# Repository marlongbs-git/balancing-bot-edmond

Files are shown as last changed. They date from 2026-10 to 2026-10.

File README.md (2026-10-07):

# edmond: the self-balancing robot!

Edmond is a two-wheeled inverted-pendulum robot built around an **STM32F303K8 (Nucleo-32)**. He balances using **LQR state feedback** designed in MATLAB/Simulink, with sensor fusion from an MPU6050, a custom 3D-printed chassis, and an OLED face that reacts when he falls.

<p align="center">
  robot_balancing_updatedgif
</p>

| | |
|---|---|
| **Controller** | Discrete LQR (`dlqr`) on `[x, ẋ, θ, θ̇]` |
| **MCU** | STM32F303K8 (Cortex-M4F, 64 KB flash) |
| **Sensing** | MPU6050 IMU (I2C) + quadrature encoders |
| **Actuation** | 2x DFRobot FIT0450 geared DC motors, L298N-based driver |
| **Extras** | Fall detection, SSD1306 OLED face |
| **Tools** | STM32CubeIDE, MATLAB/Simulink, SolidWorks |

---

## Contents

- [How edmond works](#how-he-works)
- [Repository layout](#repository-layout)
- [Firmware](#firmware)
- [Electronics](#electronics)
- [Control design](#control-design)
- [Mechanical design](#mechanical-design)
- [What I learned](#what-i-learned)
- [Status and roadmap](#status-and-roadmap)
- [Credits](#credits)

---

## How he works

Every control cycle the firmware:

1. Reads the accelerometer and gyro over I2C and fuses them with a **complementary filter** to get the pitch angle `θ` and rate `θ̇`.
2. Reads the wheel encoders for position `x` and velocity `ẋ`.
3. Computes the control effort `u = -K·[x ẋ θ θ̇]ᵀ`.
4. Converts `u` (a force) to a motor duty cycle using the motor's electrical model (torque, back-EMF, supply voltage).
5. Drives the H-bridge, or cuts power and shows the "fallen" face if the tilt exceeds the fall threshold.

## Repository layout

```
├── firmware/       STM32CubeIDE project (.ioc, Core/Src, Core/Inc)
├── electronics/    Pinout, wiring diagram, bill of materials
├── matlab/         Plant model, LQR design, Simulink model
├── mechanical/     SolidWorks parts and assembly, STEP and STL exports
├── docs/           Longer write-ups (sensor fusion, motor model, I2C debugging)
└── media/          Photos, renders, demo GIF
```

## Firmware

C on STM32 HAL. The code is split into small modules:

| File | Responsibility |
|---|---|
| `mpu6050.c/.h` | I2C driver, register reads, calibration, digital and complementary filter |
|`fit0450encoder.c/.h`| Encoder data, wheel velocity, wheel position |
| `robot_state.c/.h` | Combines IMU and encoder data into one `RobotState` |
| `control.c/.h` | LQR gains, force-to-duty conversion, PWM output |
| `ssd1306.c/.h` | Normal and fallen faces, drawn only on state changes |

See [`firmware/`](firmware/) for build instructions.

## Electronics

Pin assignments and wiring live in [`electronics/pinout.md`](electronics/pinout.md).
<p align="center">
edmond_electronicsbringup
</p>

- The MPU6050 and OLED share one I2C bus (different addresses).
- The robot is powered from a single supply through a 5 V buck converter into the Nucleo.
- I2C reliability took real effort: loose connectors caused intermittent failures, so the final build is soldered. The bus-recovery routine is documented in [`docs/i2c-debugging.md`](docs/i2c-debugging.md).

## Control design

The plant is modeled as a cart-pendulum with the wheels as the cart and the chassis as the pendulum body, including its moment of inertia. The model is linearized about the upright position, discretized, and fed to `dlqr`.

<p align="center">
cart_pend
LQR
</p>

- **State:** `[x, ẋ, θ, θ̇]`
- **Weights:** `Q` penalizes angle and angular rate much more than position; `R` penalizes motor effort.
- **Physical parameters** (masses, center of mass, inertia) come from the SolidWorks mass-properties report.

Details and the derivation are in [`matlab/`](matlab/)

## Mechanical design

The chassis is 3D printed in PLA and holds the two motors, the electronics deck, and the OLED.

<p align="center">
edmond_exploded2
front 
</p>

STEP and STL exports are in [`mechanical/`](mechanical/).

## What I learned

- Bit-level I2C register handling, and why a silent read failure is worse than a loud one.
- Why unit mismatches (degrees vs radians) are the fastest way to saturate a motor.
- How to get real physical parameters out of CAD instead of guessing them.
- Controllers can be limited by actuation, motor deadband, back-EMF spikes, and why power-supply details matter.

## Status and roadmap

- [x] Balances unaided (standing on business!)
- [x] Recovers from small pushes
- [x] Fall detection with OLED face
- [ ] Extended Kalman filter for attitude estimation
- [ ] Battery power
- [ ] Custom Motor Driver and PCB to replace perfboard

## Credits

- Phil's Lab (STM32 implementation and digital filter tutorials)
- Steve Brunton's Control Bootcamp (control and state-space modeling lectures), *Data Driven Science & Engineering
  Machine Learning, Dynamical Systems, and Control* 
- Beard and McLain, *Small Unmanned Aircraft* (attitude estimation)
- Brian Douglas's MATLAB Tech Talks (Discrete Control Theory)
- SSD1306 Files from [afiskon/stm32-ssd1306](https://github.com/afiskon/stm32-ssd1306) for OLED Drivers and face from [mjyc/table-robot-face](https://github.com/mjyc/tablet-robot-face)

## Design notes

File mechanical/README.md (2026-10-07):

# Mechanical design

The chassis is designed in SolidWorks and 3D printed in PLA. It holds the two geared motors, the electronics deck (Nucleo, MPU6050, perfboard), and the OLED face. The assembly is `robot_assemblyV4`.

<p align = "center" >
isometric
front
edmond_exploded2
</p>

## Contents

- [Files](#files)
- [Design overview](#design-overview)
- [Fasteners](#fasteners)
- [Mass properties](#mass-properties)
- [Accelerometer calibration jig](#accelerometer-calibration-jig)
- [Assembly notes](#assembly-notes)

---

## Files

| Folder / file | What it is |
|---|---|
| `*.SLDPRT`, `*.SLDASM` | Native SolidWorks parts and the full assembly |
| `stl/` | STL files for 3D printing |

## Design overview

- **Rigid body.** The legs tilt together with the head. The whole chassis is the pendulum body in the control model, and only the wheels act as the cart.
- **Motors in the legs.** The two DFRobot FIT0450 geared motors sit low, one per leg, with the wheels on their output shafts.
- **Electronics deck on top.** The Nucleo and the MPU6050 sit on a perfboard, and the OLED is mounted at the front so the face is visible.
- **Printed in PLA.** All structural parts are 3D printed.

## Fasteners

Two metric sizes are used throughout:

| Size | Typical use |
|---|---|
| **M3** | Structural joints, motor mounting, wheel and leg hardware |
| **M2** | Small electronics mounts: perfboard, OLED, sensor board |
| **M3 Heat-Set Inserts** | Leg and Head Interfacing

Using only two sizes keeps the build simple: a single hex key and screwdriver set, and no mixing of thread standards.

## Mass properties

Taken from SolidWorks (**Evaluate → Mass Properties**) relative to a coordinate system at the wheel axle, with its **X axis along the axle**, which is the axis the robot tips about.

| Property | Value |
|---|---|
| Mass (pendulum body, without wheels) | 291.35 g |
| Wheel mass (both) | 40 g |
| Center of mass (X, Y, Z) | −65.85, 60.43, −2.22 mm |
| Moment of inertia about the COM, along the axle (`Lxx`) | 604,748 g·mm² |

These values feed directly into the control model. See [`../matlab/README.md`](../matlab/README.md) for how `L` and `I` are derived from them.

## Accelerometer calibration jig

A small 3D-printed jig for calibrating the MPU6050 accelerometer. An accelerometer at rest should read exactly 1 g on whichever axis points along gravity and 0 on the other two, but real boards are off by a small amount per axis. The jig holds the sensor in repeatable, known orientations so the offsets can be measured instead of guessed.

<p align = "center" >




</p>

### Why a jig

Hand-holding the board against a table gives slightly different angles every time, and a tilt of even a degree or two shows up as an error in the offset. A printed jig with flat, square faces makes each calibration pose repeatable. It also pairs with the firmware routine, which asks for one pose per axis.

### How it is used

The firmware routine `getAccelerometerOffsets()` walks through the three axes over the serial port (USART2). For each axis:

1. It prints a prompt telling you which pose to put the board in. The X axis prompt is *"Lay Flat on Side"* and the Y axis prompt is *"Lay Flat on Back"*, followed by the Z axis pose.
2. A 5-second countdown gives you time to place the jig and let it settle.
3. It reads the accelerometer 10 times at 100 ms intervals and averages the samples.
4. It stores `offset = 1 − average` (in g) for that axis.

The three offsets are printed at the end, and they are added to the raw readings in the pitch calculation.

| Step | Pose | Axis calibrated |
|---|---|---|
| 1 | Jig on its side | X |
| 2 | Jig on its back | Y |
| 3 | Jig flat | Z |

### Axis convention

Using the jig showed that the sensor's X and Y axes are swapped relative to the robot's frame. Pitch is therefore computed with

```c
anglePitch = atan2(y_accel, sqrt(x_accel*x_accel + z_accel*z_accel)) * (180 / M_PI);
```

and the gyro rate about X is used with it. The jig is what made this visible: with the board in a known pose, the axis that read 1 g was not the one expected.

### Is it needed again?

No. The calibration only needs to be done once per sensor. After running it, the offsets were hard-coded in the firmware, so the jig is not needed to run the robot. Re-run it if the MPU6050 is replaced or re-soldered at a different angle.

### Files and print notes

- STL: `robotcalibrationjig.stl`

## Assembly notes

- Keep the center of mass centered between the wheels, so the robot tips straight and doesn't drift sideways.
- Re-run **Mass Properties** whenever you add, move, or change parts. The `m`, `L` and `I` values in the control model depend on it, and a new gain vector may be needed.
- Check that the encoder and motor wires do not rub against the wheels.

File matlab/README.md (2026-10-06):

# MATLAB / Simulink: model and LQR design

Everything needed to go from the robot's CAD mass properties to the gain vector `Kdlqr` that runs on the STM32.

**Pipeline:** SolidWorks mass properties → linearized cart-pendulum model `(A, B)` → controllability and observability checks → discretize at `Ts = 0.04 s` → discrete LQR (`dlqr`) → closed-loop pole check → Simulink simulation → paste `Kdlqr` into the firmware.

## Contents

- [Files](#files)
- [How to run](#how-to-run)
- [The model](#the-model)
- [Parameters and where they come from](#parameters-and-where-they-come-from)
- [Getting the inertia out of SolidWorks](#getting-the-inertia-out-of-solidworks)
- [LQR design](#lqr-design)
- [Results](#results)
- [Simulink model](#simulink-model)
- [Using the gains in the firmware](#using-the-gains-in-the-firmware)
- [Assumptions and limitations](#assumptions-and-limitations)
- [References](#references)

---

## Files

| File | What it is |
|---|---|
| `implementation.mlx` | **The design script for this robot.** Parameters, `A` and `B`, controllability and observability, `lqr`, `c2d`, `dlqr`, discrete pole plot. Produces `Kdlqr`. |
| `self_balancing_discreteimplementation.slx` | Simulink model of the discrete closed loop. Reads its variables from the workspace, so run `implementation.mlx` first. |
| `documentation.mlx` | Study notes following Steve Brunton's cart-pendulum example: pole placement, LQR, Kalman filter, LQG, S-Function nonlinear simulation. It uses Brunton's textbook values (`m = 1`, `M = 5`, `L = 2`), **not** this robot's parameters. |

**Requirements:** MATLAB with Control System Toolbox (`lqr`, `dlqr`, `c2d`, `ctrb`, `obsv`) and Simulink.

## How to run

1. Open `implementation.mlx` and click **Run**. It defines every variable the Simulink model needs: `F`, `G`, `Kdlqr`, `x0`, `Ts`, `Cd_simulink`, `Dd_simulink`.
2. Open `self_balancing_discreteimplementation.slx` and run it. The Scope shows the four states recovering from the initial tilt `x0`.
3. To change the starting tilt, edit `x0 = [0; 0; deg2rad(10); 0]` in the script and run it again.

## The model

The robot is a cart-pendulum. The **wheels are the cart** (mass `M`), and the **chassis, motors, electronics and head are the pendulum body** (mass `m`). The body has its own center of mass and moment of inertia, so it is not an ideal point mass on a massless rod.

State and input:

```
x = [ x   ẋ   θ   θ̇ ]ᵀ        u = force on the cart (N)
x   cart (wheel) position       θ   body angle from upright (rad)
```

Linearized about the upright position (θ = 0), with `p = I(M + m) + M m L²`:

```
      ⎡ 0    1                   0                 0 ⎤        ⎡ 0           ⎤
A  =  ⎢ 0  -(I + mL²) d / p    m² g L² / p         0 ⎥   B =  ⎢ (I + mL²)/p ⎥
      ⎢ 0    0                   0                 1 ⎥        ⎢ 0           ⎥
      ⎣ 0  -(m L d) / p        m g L (M + m) / p    0 ⎦        ⎣ m L / p     ⎦
```

Sanity check: setting `I = 0` collapses this to Brunton's point-mass cart-pendulum matrices. Open-loop, the model has exactly one unstable pole (the falling pendulum), at about **+13.9 rad/s**.

## Parameters and where they come from

| Symbol | Value | Meaning | Source |
|---|---|---|---|
| `m` | 0.29135 kg | Pendulum body mass | SolidWorks mass of `robot_assemblyV4` (291.35 g) |
| `M` | 0.040 kg | Wheel (cart) mass | Weighed |
| `L` | 0.06047 m | Distance from the wheel axle to the body's center of mass | √(Y² + Z²) of the COM in `Coordinate System1` (60.43 mm, −2.22 mm) |
| `I` | 6.04748e-4 kg·m² | Body moment of inertia **about its own center of mass**, about the axle direction | SolidWorks `Lxx` at the COM = 604,748.13 g·mm² × 1e-9 |
| `d` | 1 | Cart damping | Estimated, a tuning value |
| `g` | 9.81 m/s² | Gravity | |
| `Ts` | 0.04 s | Control loop period | Firmware loop (must match, see below) |

## Getting the inertia out of SolidWorks

The inertia is computed in CAD, not guessed.
<p align = "center" > 
robot_coordinatesystem
</p>

1. Put a **coordinate system at the wheel axle**, with its **X axis along the axle**. The robot tips about this X axis.
2. Open **Evaluate → Mass Properties** and set *Report coordinate values relative to* to that coordinate system.
3. Read three things:
   - **Mass** → `m`
   - **Center of mass** (X, Y, Z). X is along the axle (it is about half the track width, because the origin sits on one wheel), so it does not affect the lever arm. The lever arm is `L = √(Y² + Z²)`.
   - **Moments of inertia taken at the center of mass and aligned with the output coordinate system** → `Lxx`, the moment about the axle direction.
4. Convert units: g·mm² × 1e-9 = kg·m².

**Why `Lxx` at the center of mass, and not `Ixx` at the axle?** The model contains `(I + m L²)`. That term is the parallel-axis theorem (the inertia about the axle). If `I` is already the axle value, the `m L²` is counted twice. Check: `6.04748e-4 + 0.29135 × 0.06047² = 1.670e-3 kg·m²`, which matches SolidWorks' `Ixx` at the axle (1,669,992 g·mm²).

## LQR design

Cost: minimize `Σ ( xᵀ Q x + R u² )`.

```matlab
Q = diag([50 1 100 100]);   % penalties on x, xdot, theta, thetadot
R = 100;                    % penalty on control effort
```

- `Q` punishes state error. The large angle and angular-rate weights make tilt the priority. Position is allowed to drift more.
- `R` punishes control effort. A larger `R` gives a gentler, slower controller and a smaller one a more aggressive controller. Only the ratio of `Q` to `R` matters.

Steps in the script:

1. `ss(A, B, C, D)` with `C = eye(4)` (all four states are measured: encoder for `x` and `ẋ`, filtered IMU for `θ` and `θ̇`).
2. `ctrb` and `obsv` checks: both rank 4.
3. `c2d(sysc, Ts, 'zoh')` with `Ts = 0.04`.
4. Re-check controllability and observability on `(F, G)`.
5. `[Kdlqr, Ks, Kp] = dlqr(F, G, Q, R)`, applied directly to the **discrete** system. (`lqr` on the continuous model is also computed, only for comparison.)
6. Verify stability: all eigenvalues of `F − G·Kdlqr` must have magnitude < 1.

<p align = "center">
continous2discrete
</p>
## Results

Closed-loop discrete poles, all inside the unit circle:

| Pole | Magnitude |
|---|---|
| 0.0810 | 0.0810 |
| 0.9714 | 0.9714 |
| 0.8970 ± 0.0465i | 0.8982 |

Gain vector (`u = −Kdlqr · [x ẋ θ θ̇]ᵀ`, SI units, angle in radians):

```
Kdlqr ≈ [ -0.2045   -1.4142    5.5034    0.4909 ]
```

<p align="center">
Discrete Closed-Loop Poles
simulinkblockdiagram
</p>
<p align = "center">
10degdisturbance
</p>

The Simulink runs start tilted at 10°, 20° and 30° with all states returning to zero.

## Simulink model

`self_balancing_discreteimplementation.slx` is a minimal discrete closed loop:

- **Discrete State Space** block: `A = F`, `B = G`, `C = Cd_simulink` (identity), `D = Dd_simulink`, initial condition `x0`, sample time `Ts`.
- **Gain** block (`−Kdlqr`, matrix multiply): state feedback `u = −K x` fed back into the plant.
- **Scope** and **To Workspace**: for viewing and exporting the state trajectories.

It simulates the **linear** model, so it answers "does the design stabilize the linearized plant?", not "will the real robot behave identically?".

## Using the gains in the firmware

1. Run `implementation.mlx` and read `Kdlqr` (add `disp(Kdlqr)` to print it).
2. Paste the four numbers into `setControlGains(...)` in `firmware/Core/Src/control.c`.
3. Keep the same state order `[x, ẋ, θ, θ̇]`, SI units, and angles in **radians**. The firmware stores the pitch in degrees and converts before applying `K`.
4. `Ts = 0.04` must match the actual control loop period, because the discrete gains depend on it. If the loop runs at a different rate, change `Ts` and re-run the script.
5. Convert force to motor duty with the motor model (see the firmware README).

## Assumptions and limitations

- The model is **linearized about upright**, valid for small angles.
- The only input is a force on the cart. The motor, driver and deadband are handled afterward by the force-to-duty conversion, not inside the LQR model.
- Damping `d` is an estimate, not a measured value.
- Wheel inertia is represented only through the cart mass `M`.
- No sensor noise or state estimator in the loop. The measured states come from the complementary filter and encoder directly.
- Tuning of `Q` and `R` was done by experiment on the robot, not by an optimization criterion.

## References

- Steven L. Brunton, *Control Bootcamp* lectures and *Data-Driven Science and Engineering* (cart-pendulum, LQR, LQG)
- University of Michigan CTMS, *Inverted Pendulum: System Modeling* (the form with body inertia `I`)
- MathWorks documentation: `lqr`, `dlqr`, `c2d`, `ctrb`, `obsv`

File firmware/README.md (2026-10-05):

# Firmware

STM32CubeIDE project for the self-balancing robot (STM32F303K8, Nucleo-32). C on the STM32 HAL.

## Contents

- [Overview](#overview)
- [Modules](#modules)
- [Control path](#control-path)
- [Setup and build](#setup-and-build)
- [Running and tuning](#running-and-tuning)
- [Challenges](#challenges)
- [Known limitations](#known-limitations)

---

## Overview

The main loop does the same thing every cycle:
<p align="center">
firmware_decision
</p>

## Modules

| Module | Responsibility |
|---|---|
| `mpu6050.c/.h` | I2C driver for the IMU: register reads (16-bit values assembled with bit shifts), calibration, accelerometer pitch, gyro rate, complementary filter, I2C error handling and bus recovery |
| `robot_state.c/.h` | Builds one `RobotState` (x, v, θ, ω, tipped) from the IMU and encoder. Everything downstream reads this struct |
| `control.c/.h` | LQR gains, control effort, force-to-duty conversion, deadband handling, PWM and direction output |
| `ssd1306` + face code | OLED driver and the two face bitmaps. Redrawn only when the fallen/normal state changes |
| `main.c` | Peripheral init (generated by CubeMX) and the control loop |

## Control path

| Function | What it does |
|---|---|
| `getRobotState()` | Returns the latest fused state. Single entry point for sensor data |
| `updateOrientationState()` | Reads accel and gyro once each, runs `compFilter()`, stores θ and θ̇ |
| `compFilter(accelAngle, gyroRate, alpha)` | `θ = α(θ + gyro·dt) + (1−α)·θ_accel`. Guards the first call and clamps `dt` |
| `setControlGains(kx, kv, ktheta, komega)` | Loads the gains from the MATLAB LQR design |
| `computeControlEffort(&state)` | `u = -K·x`. Converts degrees to radians first, because K was designed in radians |
| `computeControlDuty(u, v)` | Turns a force into a duty cycle using the motor model (below) |
| `setPWMControl(duty)` | Sign sets the direction pins, magnitude sets the `TIM1` compare value |
| `updateFaceDisplay(tipped)` | Draws a face only on a state change, to avoid blocking the I2C bus |
| `printRobotState(&state)` | UART debug output for plotting |

### Force to duty

LQR outputs a force at the wheel. The motor needs a voltage, so:

```c
wheelOmega = v / r;                                  // wheel speed from cart velocity
torque     = u * r;                                  // force -> wheel torque
V          = (torque + ktkvOverR * wheelOmega) / ktOverR;  // add back-EMF term
duty       = V / supplyVoltage;                      // normalise to PWM
```

Motor constants (FIT0450): `Ra ≈ 2.14 Ω`, `Kt ≈ 0.028 N·m/A`, `Kv ≈ 0.336 V·s/rad`.

The motor constants were gathered using calculations from [DFRobot's FIT0450 Datasheet](https://wiki.dfrobot.com/fit0450/#tech_specs)

### Fall detection

If `|θ|` exceeds the tilt threshold, `state.tipped` is set, PWM goes to zero and the fallen face is shown. `updateFaceDisplay()` is called every loop (outside the tipped branch) so the face returns to normal once the robot is upright again.

```c
#define FALL_THRESHOLD_DEGREES 40.0f
#define RECOVERY_THRESHOLD_DEGREES 5.0f
```

```c
static bool checkFallDetection(float thetaDeg) {
	static bool tippedLatch = false;

	if(!tippedLatch && fabs(thetaDeg) > FALL_THRESHOLD_DEGREES){
		tippedLatch = true;
	}else if (tippedLatch && fabs(thetaDeg) < RECOVERY_THRESHOLD_DEGREES){
		tippedLatch = false;
	}
	return tippedLatch;
}
```
## Setup and build

**Requirements:** STM32CubeIDE, an ST-LINK (built into the Nucleo), a serial terminal.

1. Clone the repo and open `firmware/` in STM32CubeIDE (*File → Open Projects from File System*).
2. Open the `.ioc` file to check the peripheral configuration. CubeMX is the source of truth for pins.
3. Build with the Release configuration (`-Os`), then flash with the green Run button.
4. Open a serial terminal on the ST-LINK virtual COM port, **USART2 at 38400 baud** 

Peripheral summary (see [`../electronics/pinout.md`](../electronics/pinout.md) for pins):

| Peripheral | Use |
|---|---|
| `I2C1` | MPU6050 and SSD1306 on one bus |
| `TIM1` CH1 / CH4 | Motor PWM |
| `TIM2` | Encoder interface |
| `USART2` | Debug prints |

## Running and tuning

1. Flash new robot code with the USB connected exclusively.
2. Remove USB Connector.
3. Power up with the robot held upright and still. The gyro offset is calibrated at startup.
4. Release it. It should hold itself near vertical.
5. Gains are set in one place via `setControlGains(...)`. Regenerate K in `matlab/` and paste the new values.

LQR tuning intuition: `Q` penalizes state error, `R` penalizes motor effort, and only their ratio matters. Raising the θ and θ̇ weights makes the robot react harder to tilt. Raising `R` makes it gentler and slower.

## Challenges

- **I2C failures.** Intermittent acknowledge-failure and arbitration-lost errors came from loose connectors. Soldering fixed the root cause; status checks, timeouts and bus recovery make the driver fail loudly. See [`../docs/i2c-debugging.md`](../docs/i2c-debugging.md).
- **Degrees vs radians.** The state is stored in degrees but K was designed in radians. Missing the conversion saturated the motors.
- **OLED blocks the sensor loop.** A full refresh sends about 1 KB over I2C and takes roughly 8 to 10 ms. The face is redrawn only on state changes.

## Known limitations

- Only one encoder is wired, so position and velocity come from a single wheel and assumed the same.
- No battery operation yet (bench supply at 7.1 V fed to a 5 V buck converter).
- No driving command yet; the controller only holds the upright position.
- Complementary filter only; an EKF is on the roadmap.
- Motor will quickly saturate after prolonged operation for best performance only operate at small intervals.

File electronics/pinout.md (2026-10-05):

# Pinout

Board: **STM32 Nucleo-F303K8** (Nucleo-32, Arduino Nano footprint).
The "Board pin" column is the label printed on the Nucleo; the "MCU pin" column is the STM32 pin it connects to.

<p align="center">
stm32pinout
</p>

## Connection table

| Board pin | MCU pin | Function | Connected to |
|---|---|---|---|
| A0 | PA0 | `TIM2_CH1` (encoder A) | FIT0450 encoder, channel A |
| A1 | PA1 | `TIM2_CH2` (encoder B) | FIT0450 encoder, channel B |
| D0 | PA10 | GPIO output (direction) | Motor driver M1 |
| D2 | PA12 | GPIO output (direction) | Motor driver M2 |
| D4 | PB7 | `I2C1_SDA` | MPU6050 SDA, OLED SDA |
| D5 | PB6 | `I2C1_SCL` | MPU6050 SCL, OLED SCL |
| D9 | PA8 | `TIM1_CH1` (PWM) | Motor driver E1 (enable / speed) |
| D10 | PA11 | `TIM1_CH4` (PWM) | Motor driver E2 (enable / speed) |
| 3V3 | - | Power | MPU6050 VCC (TODO: confirm whether the OLED and encoder are also on 3V3) |
| 5V | - | Power in | 5 V buck converter output (see below) |
| GND | - | Ground | Common ground for everything |
| PA2 / PA15 | - | `USART2` TX / RX | ST-LINK virtual COM port (debug prints) |

> Only one encoder (on A0/A1) is wired. Position and velocity come from that wheel, even though both motors have encoders.

## I2C bus

| Device | Address (7-bit) | Notes |
|---|---|---|
| MPU6050 | `0x68` | Default address (AD0 low). Confirm against `DEVICE_ADDRESS` in the firmware. |
| SSD1306 OLED | `0x3C` | 128x64, used for the robot face. |

Both devices share the same two wires. Different addresses mean no conflict, but a full OLED refresh sends about 1 KB over the bus and blocks the CPU, so the face is only redrawn when the state changes (see the firmware notes).

## Motor driver (DFRobot DRI0002, L298N-based)

| Signal | Meaning |
|---|---|
| `M1`, `M2` | Direction (HIGH / LOW) for each motor |
| `E1`, `E2` | Enable pins, driven with PWM for speed |

PWM runs on **TIM1**, not TIM3. TIM3's channels collided with the I2C pins during development, which is why the PWM outputs moved to PA8 and PA11.

## Power

```
DC supply 7.1V ────────────────► motor driver (motor supply)
            │
            └─► 5 V buck converter ─► Nucleo +5V pin ─► on-board regulator ─► 3V3 rail
                                                         (MPU6050, OLED, encoder)
```

- One bench supply powers the whole robot.
- The motor driver takes the raw supply voltage. The Nucleo, IMU, OLED and encoder run from a regulated 5 V buck converter output.
- Back-EMF spikes appear on the supply when the motors reverse quickly, so the buck converter is chosen with input headroom.
- **Remove SB9** on the Nucleo if you run it from the +5V pin without USB connected (Already removed).
- All grounds (supply, driver, Nucleo, encoder, sensors) must be common, otherwise the encoder readings are unreliable.

## Wiring notes

- Soldered connections only for Buck Converter and IMU. Vibrations from movement and cheap headers caused I2C Failure for the sensor (acknowledge failures and arbitration-lost errors).
- Keep the I2C wires short and away from the motor wires.
- If the bus ever locks up, the firmware runs a bus-recovery routine (toggle SCL up to 9 times, send a STOP, re-initialize the peripheral).

## Bill of materials (electronics)

| Part | Qty | Notes |
|---|---|---|
| STM32 Nucleo-F303K8 | 1 | Main controller |
| MPU6050 breakout | 1 | I2C IMU |
| DFRobot FIT0450 geared DC motor with encoder | 2 | 120:1 gearbox |
| DFRobot DRI0002 dual motor driver | 1 | L298N-based |
| 0.96" SSD1306 I2C OLED, 128x64 | 1 | I2C OLED Robot face |
| 5 V buck converter (MPM3610 breakout) | 1 | 6-21 V in, 1.2 A out |
| Perfboard, wire, headers | - | Soldered build |

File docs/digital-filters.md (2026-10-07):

# Digital Filtering in Edmond

The robot balances by knowing its tilt angle, but neither tilt sensor is good enough on its own. The accelerometer gives a noisy angle that jumps around with every vibration. The gyroscope gives a smooth angular rate, but its angle slowly drifts. Two small digital filters clean this up:

| Filter | What it does | Where it is used |
|---|---|---|
| **EMA low-pass** (first-order IIR) | Smooths noisy readings | Each accelerometer axis (α = 0.2) and the gyro rate (α = 0.5) |
| **Complementary filter** | Blends the accelerometer angle and the gyro rate into one stable pitch | Final pitch estimate used by the controller |

## Contents

- [The pipeline](#the-pipeline)
- [1. EMA filter (first-order IIR)](#1-ema-filter-first-order-iir)
- [2. Complementary filter](#2-complementary-filter)
- [Trade-offs](#trade-offs)
- [Tuning tips](#tuning-tips)
- [References](#references)

---

## The pipeline

```mermaid
flowchart LR
    A["Accelerometer<br/>x, y, z"] --> B["EMA low-pass<br/>α = 0.2<br/>(each axis)"]
    B --> C["Pitch angle<br/>atan2(y, √(x² + z²))"]
    G["Gyro rate<br/>about X"] --> H["EMA low-pass<br/>α = 0.5"]
    C --> F["Complementary<br/>filter"]
    H --> F
    F --> O["Filtered pitch θ<br/>to the controller"]
```

Pitch represents the angle of the top of the robot's head relative to the horizontal.

---

## 1. EMA filter (first-order IIR)

<p align="center">
  First-order IIR (EMA) filter
</p>

### The idea

An **exponential moving average (EMA)** keeps a running value and nudges it toward each new sample. Instead of storing the last 10 readings and averaging them, it only remembers **one number**, the previous output. That makes it cheap enough for a small microcontroller.

$$ y[n] = \alpha \, x[n] + (1 - \alpha) \, y[n-1] $$

- `x[n]` is the new sample and `y[n-1]` is the previous filtered output.
- `α` (alpha) between 0 and 1 sets how much you **trust the new sample**.

It is called a first-order **IIR** (infinite impulse response) filter because the output feeds back into itself. One delay element is all it needs.

### Choosing alpha

| α | Behavior | Result |
|---|---|---|
| Close to 1 | Mostly the new sample | Little smoothing, fast response |
| Close to 0 | Mostly the old output | Heavy smoothing, slow response |

For reference, if the filter runs every 40 ms, α = 0.2 gives a time constant of about 0.18 s, and α = 0.5 about 0.06 s. That is roughly how long the output takes to reach 63% of a sudden step.

### Code

```c
float digitalLowPassFilter(float input, float alpha, float *state) {
    // y = alpha * x + (1 - alpha) * y_prev
    *state = alpha * input + (1.0f - alpha) * (*state);
    return *state;
}
```

The `state` pointer holds the previous output. **Each signal needs its own state variable.** The three accelerometer axes use three separate states, so one axis can never overwrite another's history.

### How it is applied to the accelerometer

Each raw axis is filtered, and then the pitch angle is calculated from the filtered values:

```c
float alpha = 0.2f;

static float lpfStateXAccel = 0.0f;
static float lpfStateYAccel = 0.0f;
static float lpfStateZAccel = 0.0f;

x_accelLSBF = digitalLowPassFilter(x_accelLSB, alpha, &lpfStateXAccel);
y_accelLSBF = digitalLowPassFilter(y_accelLSB, alpha, &lpfStateYAccel);
z_accelLSBF = digitalLowPassFilter(z_accelLSB, alpha, &lpfStateZAccel);

anglePitchFiltered = atan2(y_accelLSBF,
                           sqrt(x_accelLSBF * x_accelLSBF + z_accelLSBF * z_accelLSBF))
                     * (180 / M_PI);
```

The full function, including the I2C reads and error handling, is in [`firmware/Core/Src/mpu6050.c`](../firmware/Core/Src).

### Result

The plot compares the unfiltered pitch from the accelerometer (**pink**) with the filtered pitch at α = 0.2 (**green**). The filtered trace is visibly smoother, with a small lag behind the raw one.

<p align="center">
  Unfiltered pitch (pink) vs filtered pitch with alpha 0.2 (green)
</p>

---

## 2. Complementary filter

<p align="center">
  Complementary filter
</p>

### The problem

| Sensor | Good at | Bad at |
|---|---|---|
| Accelerometer angle | Long-term accuracy. Gravity always points down. | Noisy. Vibration and acceleration corrupt it. |
| Gyroscope (integrated) | Short-term accuracy. Smooth and responsive. | **Drift.** Small errors add up over time. |

Each one is strong where the other is weak, which is why they are called *complementary*.

### The idea

Use the gyro for fast changes and let the accelerometer slowly pull the result back toward the true angle:

$$ \theta[n] = \alpha \left( \theta[n-1] + \omega \cdot \Delta t \right) + (1 - \alpha) \, \theta_{\text{accel}} $$

- `θ[n-1] + ω·Δt` is the previous angle plus the gyro's rotation since the last step.
- `θ_accel` is the pitch from the accelerometer.
- `α` is usually close to 1 (for example 0.95 to 0.99), so the **gyro dominates** over short times and the accelerometer corrects the drift over longer times.

> **Watch the meaning of alpha.** In the EMA filter, α weights the **new sample**. In the complementary filter, α weights the **gyro**. They are different filters with opposite conventions, so values are not interchangeable.

Edmond uses the complementary alpha of 0.95.

### Code

```c
float compFilter(float anglePitch, float gyroAngularRate, float alpha) {
    static float    compFilterOutput = 0.0f;
    static uint32_t getTickOld       = 0;
    static uint8_t  firstRun         = 1;

    uint32_t currentTick = HAL_GetTick();
    float dt;

    if (firstRun) {            // no previous tick yet, so don't integrate
        dt = 0.0f;
        firstRun = 0;
    } else {
        dt = (currentTick - getTickOld) / 1000.0f;   // seconds
        if (dt > 0.05f) dt = 0.05f;                  // ignore long gaps
    }
    getTickOld = currentTick;

    compFilterOutput = alpha * (compFilterOutput + gyroAngularRate * dt)
                     + (1.0f - alpha) * anglePitch;

    return compFilterOutput;
}
```

Two small guards matter in practice:

- **First call.** Without it, `dt` is computed from a tick counter that starts at 0, so the first integration step is huge and the angle starts far from zero.
- **`dt` clamp.** If the loop stalls (an I2C retry, for example), a long `dt` would add a large jump to the angle.

---

## Trade-offs

Every filter adds **delay**. The more smoothing, the further the filtered value lags behind the real motion. For a balancing robot, that lag works against the controller, which needs to react quickly to tilt.

How much delay is acceptable depends on the control loop speed and how the sensor data is read and passed along. For Edmond, the lag is small enough that the robot balances. A faster or more demanding system would need the filters tuned for its specific case, for example by optimizing them in MATLAB.

Edmond's choice is also deliberately simple: two light filters that need almost no memory or computing time on the STM32.

## Tuning tips

1. **Change one alpha at a time** and compare the plots against the unfiltered signal.
2. **Too much smoothing** shows up as slow recovery and oscillation. **Too little** shows up as jitter in the motors.
3. **Stack filters carefully.** The accelerometer here is smoothed by the EMA *and* then the complementary filter, which also low-passes it. If the response feels sluggish, try less smoothing on the accelerometer first.
4. **Seed the EMA state** with the first sample, not 0, to avoid a short ramp-up at startup.

## References

- Phil's Lab, [*The Simplest Digital Filter (STM32 Implementation), Phil's Lab #92*](https://www.youtube.com/watch?v=1e_ZB8p5n6s)
- Phil's Lab, [*Complementary Filter - Sensor Fusion #2, Phil's Lab #34*](https://www.youtube.com/watch?v=BUW2OdAtzBw&xstg=CAMSEBUJ_b-oH-PhF0yjBgaukzY%3D)
- Phil's Lab, [*IIR Filters - Theory and Implementation (STM32), Phil's Lab #32*](https://www.youtube.com/watch?v=QRMe02kzVkA&xstg=CAMSEBUJ_b-oH-PhF0yjBgaukzY%3D)

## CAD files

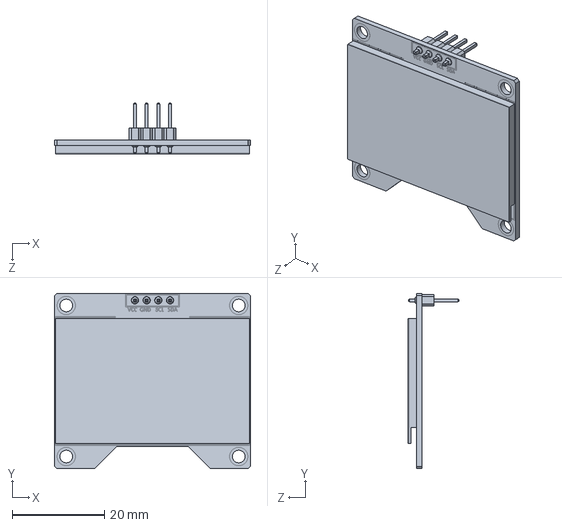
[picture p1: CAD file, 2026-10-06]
mechanical/parts/OLED Display 128x64.SLDPRT
42.5 x 38.0 x 11.1 mm

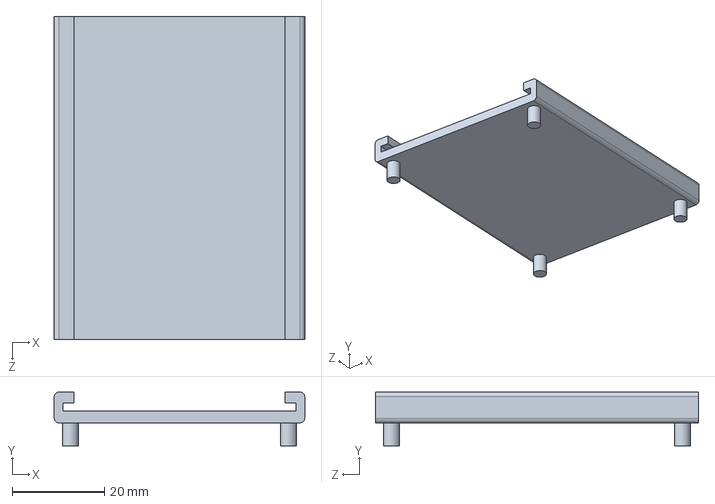
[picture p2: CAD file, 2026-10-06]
mechanical/parts/robothead_perf.SLDPRT
54.3 x 11.7 x 70.0 mm

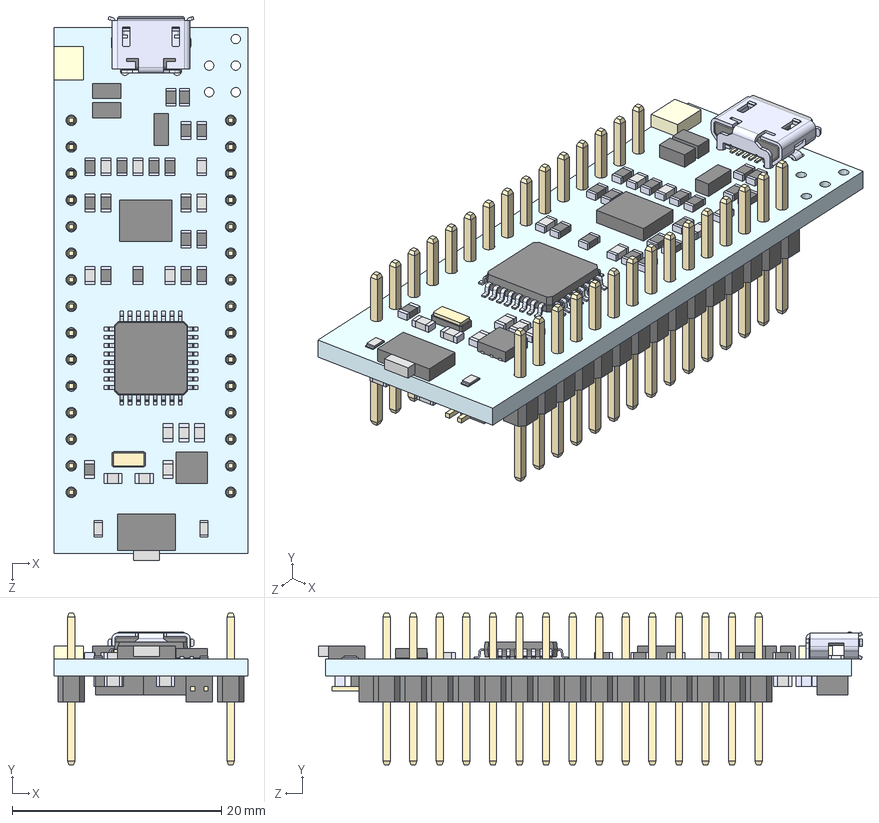
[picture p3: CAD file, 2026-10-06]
mechanical/parts/NUCLEO-F303K8.STEP
18.5 x 14.5 x 52.0 mm
mb1180c
LD39050PU33R-Nucleo
STM32F103CBT6-nucleo
header x2
lqpf1

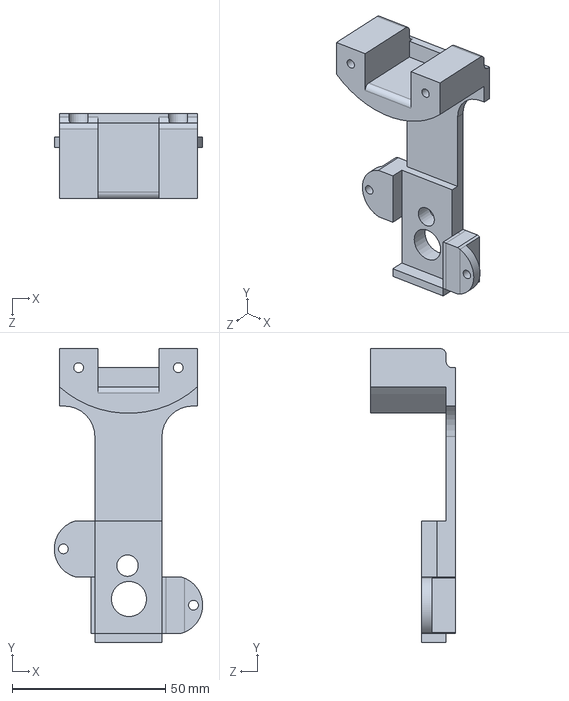
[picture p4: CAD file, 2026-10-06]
mechanical/parts/robot_leg_p1.SLDPRT
48.4 x 95.9 x 27.6 mm

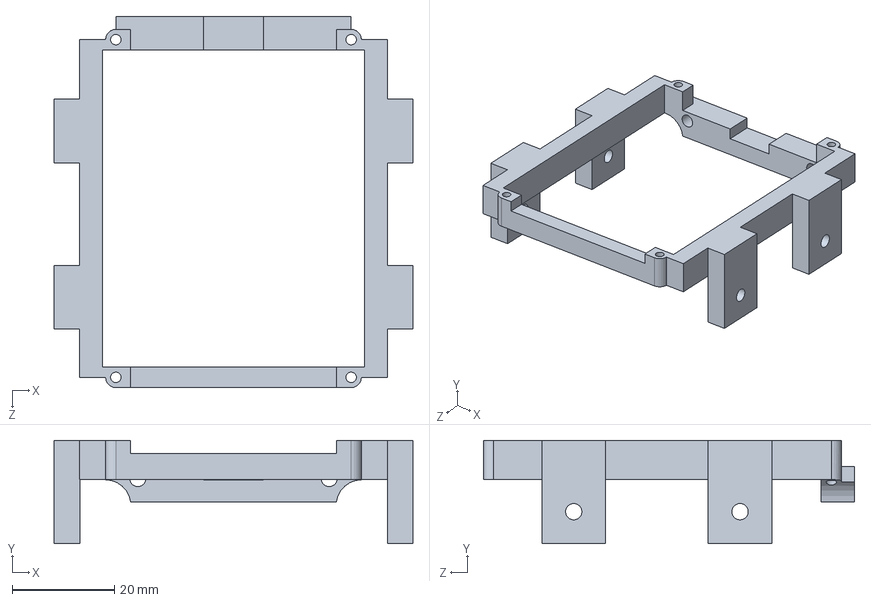
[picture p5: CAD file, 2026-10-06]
mechanical/parts/robothead_drivertop.SLDPRT
70.2 x 20.2 x 72.5 mm

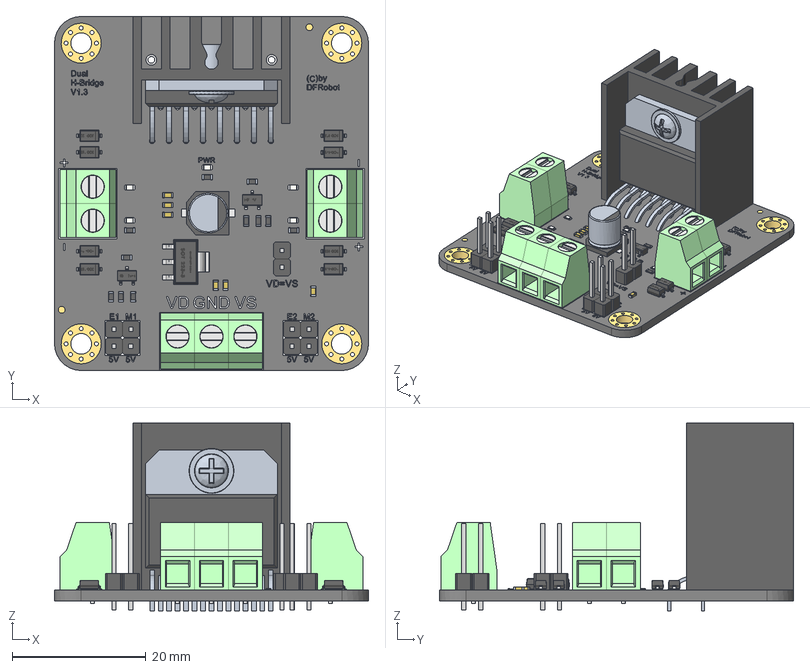
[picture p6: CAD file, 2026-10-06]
mechanical/parts/DRI0002_l298n-dual-motor-controller-module_stpfile_1.3.stp
47.0 x 53.0 x 28.1 mm

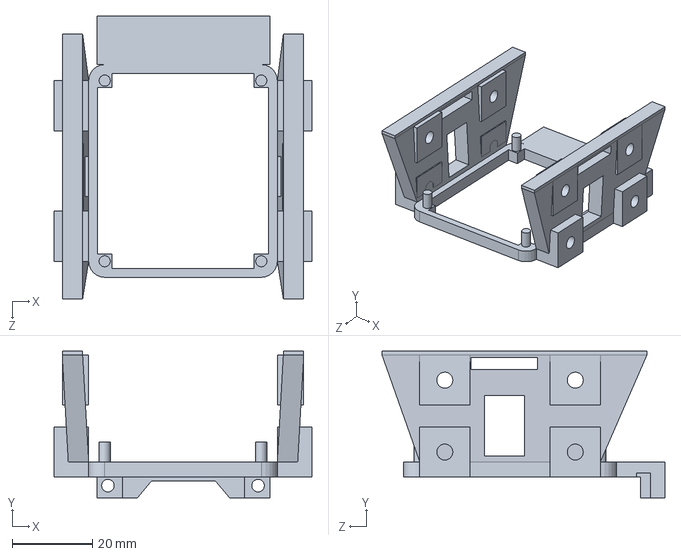
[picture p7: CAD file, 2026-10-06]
mechanical/parts/robothead_driverbottom.SLDPRT
64.2 x 36.6 x 70.5 mm

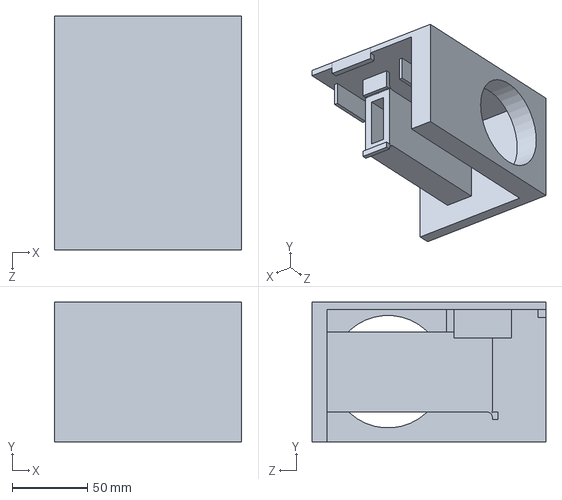
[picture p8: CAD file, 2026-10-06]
mechanical/parts/robotcalibrationjig.SLDPRT
124.4 x 93.0 x 155.6 mm

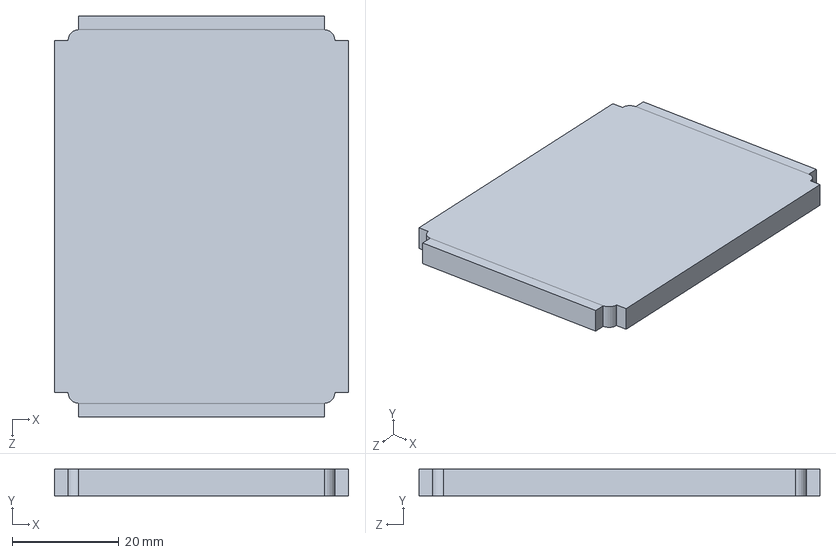
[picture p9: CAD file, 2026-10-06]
mechanical/parts/robothead_driver.SLDPRT
55.1 x 5.00 x 75.1 mm

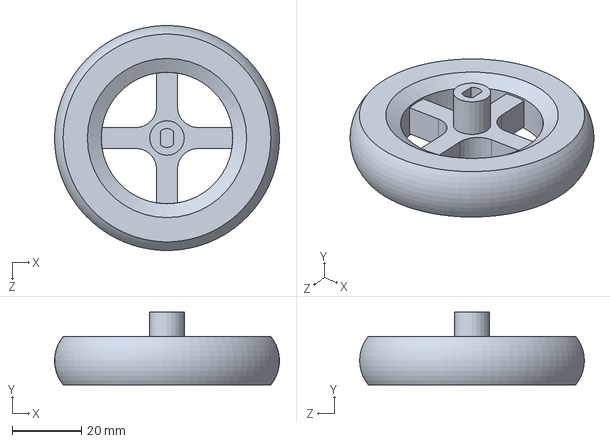
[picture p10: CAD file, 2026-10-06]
mechanical/parts/robotwheel.SLDPRT
65.0 x 21.0 x 64.9 mm

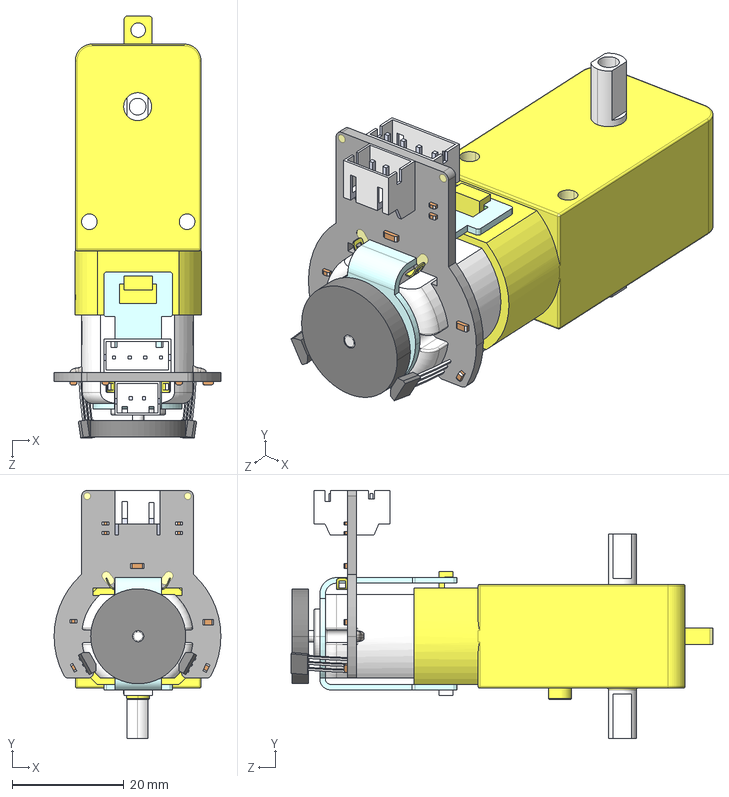
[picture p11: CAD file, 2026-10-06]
mechanical/parts/FIT0450.STEP
29.9 x 44.4 x 75.5 mm
黄色电机（竖向双轴）
棠遠
编码器PCB尺寸
零件2^装配体2 x 2

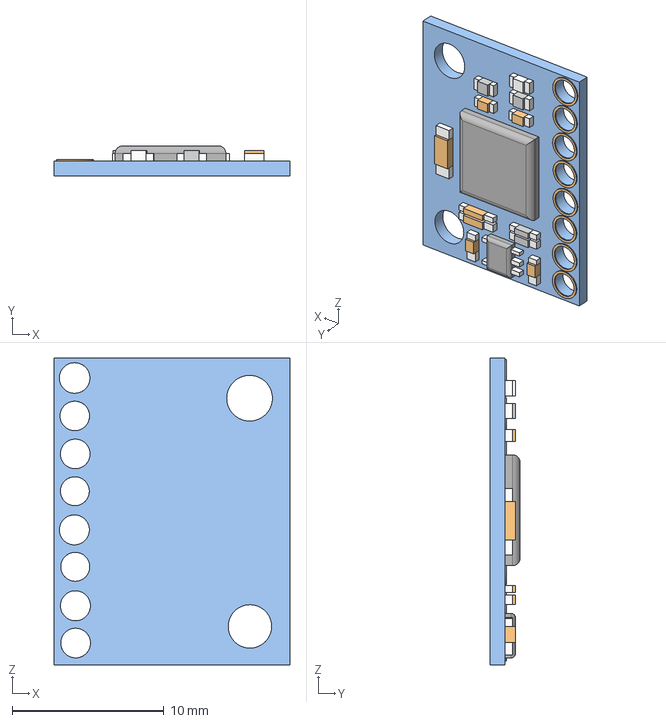
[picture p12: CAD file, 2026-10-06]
mechanical/parts/MPU6050 v2.step
15.6 x 2.00 x 20.3 mm

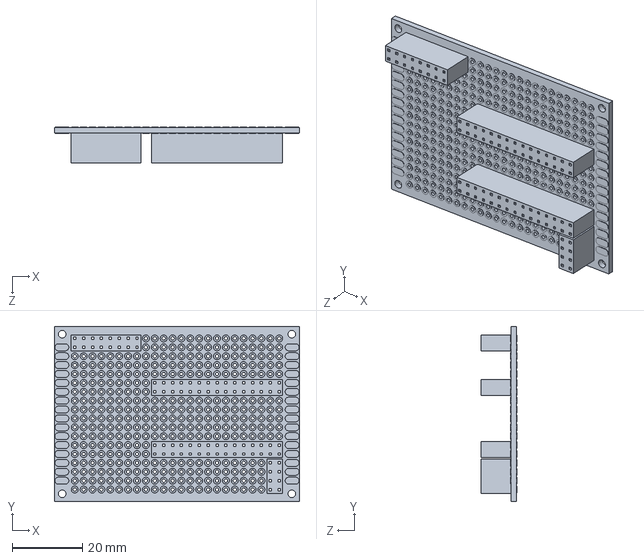
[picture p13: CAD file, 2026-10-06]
mechanical/parts/pcb_5x7_withheaders.SLDPRT
70.0 x 50.0 x 10.2 mm

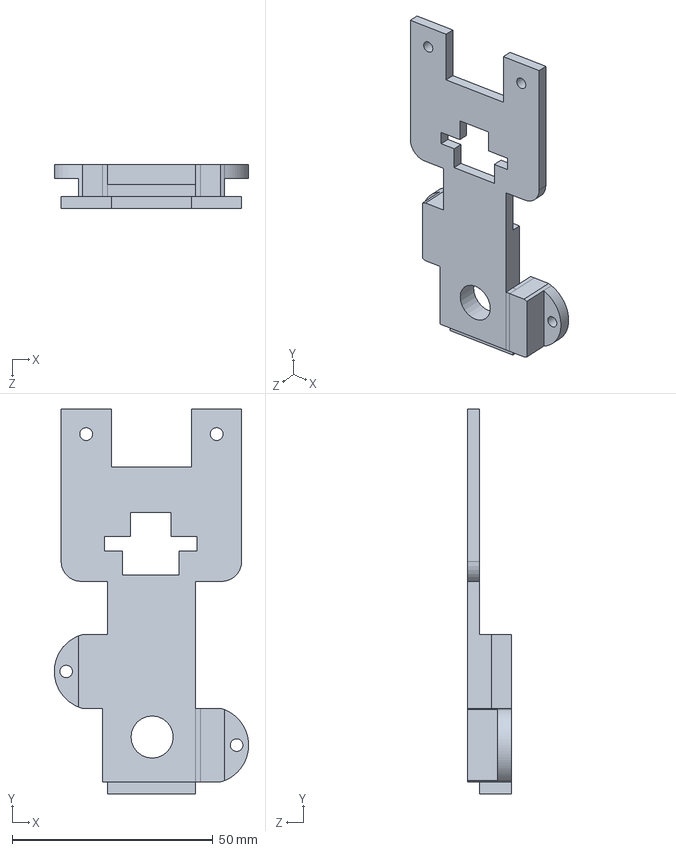
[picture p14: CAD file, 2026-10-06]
mechanical/parts/robot_leg_p2.SLDPRT
48.4 x 95.9 x 11.0 mm

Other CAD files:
mechanical/assembly/robot_assemblyV4.SLDASM
mechanical/stl/robot_leg_p1.STL
mechanical/stl/robot_leg_p2.STL
mechanical/stl/robotcalibrationjig.STL
mechanical/stl/robothead_driverbottom.STL
mechanical/stl/robothead_drivertop.STL

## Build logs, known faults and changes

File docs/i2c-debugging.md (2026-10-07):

# I2C Debugging and Reliable Sensor Reads

Edmond's MPU6050 (IMU) and SSD1306 (OLED face) share one I2C bus on an STM32F303K8 Nucleo. Getting that bus reliable took longer than most of the control work, and the problems were instructive. This page covers:

- what the error codes were and what each one told us,
- the fix that keeps the robot running on the **last good reading** when a transfer fails,
- why putting the display on the same bus as the sensor slowed the control loop, and what to do about it,
- a troubleshooting guide and reference links for I2C on STM32 Nucleo boards.

## Contents

- [Setup](#setup)
- [How the problem showed up](#how-the-problem-showed-up)
- [Reading the error codes](#reading-the-error-codes)
- [What the codes told us about Edmond](#what-the-codes-told-us-about-edmond)
- [The fix: check, retry, recover, keep the last good value](#the-fix-check-retry-recover-keep-the-last-good-value)
- [Sensor and OLED on one bus](#sensor-and-oled-on-one-bus)
- [Lessons learned](#lessons-learned)
- [References](#references)

---

## Setup

| Item | Value |
|---|---|
| MCU | STM32F303K8 (Nucleo-32) |
| Peripheral | `I2C1`, pins `PB6` (SCL) and `PB7` (SDA) |
| Devices | MPU6050 at `0x68`, SSD1306 OLED at `0x3C` |
| HAL calls | Blocking: `HAL_I2C_Mem_Read`, `HAL_I2C_Master_Transmit` |

Pins and wiring are in [`../electronics/pinout.md`](../electronics/pinout.md).

My I2C BUS runs at 100kHz.

## How the problem showed up

The sensor loop read the IMU every cycle, and now and then a read would fail. Sometimes the angle froze, sometimes the robot jerked, sometimes the loop stalled altogether. In the early bring-up the MPU6050 wasn't found at all, and later the failures were intermittent. They were hard to chase because they were intermittent, so it was worth printing the error code instead of just checking for success or failure.

## Reading the error codes

After any failed HAL I2C call, `HAL_I2C_GetError(&hi2c1)` returns a bitmask. The bits are defined in [`stm32f3xx_hal_i2c.h`](https://github.com/STMicroelectronics/stm32f3xx_hal_driver/blob/master/Inc/stm32f3xx_hal_i2c.h):

| Bit | Name | Value | Meaning in plain terms |
|---|---|---|---|
| 0 | `HAL_I2C_ERROR_BERR` | `0x01` | **Bus error.** A START or STOP showed up at an illegal moment, usually from noise or a glitch. |
| 1 | `HAL_I2C_ERROR_ARLO` | `0x02` | **Arbitration lost.** The MCU put a 1 on SDA but read back a 0, so something else was driving the line low. |
| 2 | `HAL_I2C_ERROR_AF` | `0x04` | **Acknowledge failure.** Nobody pulled SDA low to ACK. The address or data byte went unanswered. |
| 3 | `HAL_I2C_ERROR_OVR` | `0x08` | **Overrun/underrun.** Mostly relevant in slave mode. |
| 4 | `HAL_I2C_ERROR_DMA` | `0x10` | DMA transfer error. |
| 5 | `HAL_I2C_ERROR_TIMEOUT` | `0x20` | **Timeout.** The transfer did not finish in the time given. |

Bits can combine, so decode the hex by splitting it into its bits:

```
0x22 = 0x20 + 0x02  =  TIMEOUT + ARLO
0x04                =  AF
```

Print it as hex in your error handler. It costs one line and saves hours:

```c
HAL_StatusTypeDef status = HAL_I2C_Mem_Read(&hi2c1, DEVICE_ADDRESS << 1,
                                            REG_DATA_GYROX, I2C_MEMADD_SIZE_8BIT,
                                            buf, 2, I2C_TIMEOUT_MS);
if (status != HAL_OK) {
    uint32_t err = HAL_I2C_GetError(&hi2c1);
    sprintf(msg, "I2C FAILED status=%d error=0x%lX\r\n", status, err);
    HAL_UART_Transmit(&huart2, (uint8_t*)msg, strlen(msg), 100);
}
```

## What the codes told us about Edmond

Two codes appeared in the debugger:

| Code | Decoded | What it means |
|---|---|---|
| `0x4` | `AF` | The bus itself worked, and the MCU sent the address, but no device answered. The sensor was either unpowered, disconnected, or not listening at that moment. |
| `0x22` | `ARLO` + `TIMEOUT` | The MCU lost control of SDA, then the transfer never finished. Something was holding or disturbing the line mid-transaction. |

Taken together: **the I2C peripheral and the firmware configuration were fine.** The two codes point to an *electrical* problem on the wires: connections that broke momentarily. A connector that opens for a moment mid-byte leaves the sensor holding SDA low part way through a transfer. The MCU then reads back the wrong level (`ARLO`) and waits for a transfer that cannot complete (`TIMEOUT`). When the connector is open at the address phase, nobody answers (`AF`).

That matched what we saw physically. The failures were intermittent; they changed when the wires moved, and they went away after **the loose connectors were replaced with soldered joints**.

This is why the code was worth decoding:

| If you see | Suspect first |
|---|---|
| `AF` (`0x4`) on every try | Wrong address, wrong wiring, no power, or a dead device |
| `AF` now and then | Loose or intermittent connection |
| `ARLO`, `BERR` | Noise, a loose wire, a short, or a device stuck holding SDA |
| `TIMEOUT` alone | Bus stuck busy, clock stretching, or a timeout that is too short |
| Nothing works, even after power-up | I2C timing register or pin setup (see below) |

## The fix: check, retry, recover, keep the last good value

The original code issued the reads and used the result without checking. A failed read left a stale or garbage buffer, which turned into a nonsense angle. The fix has four parts:

1. **Check every transaction.** Use a finite timeout (`I2C_TIMEOUT_MS`), never `HAL_MAX_DELAY`. A blocking call with an infinite timeout can hang the whole control loop on a stuck bus.
2. **Report the cause.** Print the status and hex error code, as above.
3. **Recover the bus** if failures keep happening. After more than 5 failures in a row, run `I2C_BusRecovery()`.
4. **Return the last good reading** on a failure, so the filter and controller keep getting a sensible number instead of garbage.

```c
float mpu6050_getGyroRate(float GxOffsetError, float GyOffsetError, float GzOffsetError)
{
    uint8_t datagy_x[2];
    static float    lastGoodGyroLSB     = 0.0f;   // remembered between calls
    static uint16_t consecutiveFailures = 0;

    HAL_StatusTypeDef status = HAL_I2C_Mem_Read(&hi2c1, (DEVICE_ADDRESS << 1) + 1,
                                  REG_DATA_GYROX, 1, datagy_x, 2, I2C_TIMEOUT_MS);
    if (status != HAL_OK) {
        uint32_t errorCode = HAL_I2C_GetError(&hi2c1);
        sprintf(printstringArcTan, "I2C FAILED status=%d error=0x%lX \r\n", status, errorCode);
        HAL_UART_Transmit(&huart2, (uint8_t*)printstringArcTan, strlen(printstringArcTan), 100);

        if (++consecutiveFailures > 5) {
            I2C_BusRecovery();
            consecutiveFailures = 0;
        }
        return lastGoodGyroLSB;                   // keep the last good reading
    }
    consecutiveFailures = 0;

    // ... convert, apply offset, low-pass filter ...
    lastGoodGyroLSB = x_gyroLSBFiltered;
    return lastGoodGyroLSB;
}
```

The accelerometer function follows the same pattern with its own `lastGoodPitchFiltered`. Each function keeps its own `static` last-good value and its own failure counter.

### What bus recovery does

If a device is left holding SDA low (a transfer was cut off mid-byte), it stays that way until it sees enough clock pulses to finish the byte it thinks it is sending. `I2C_BusRecovery()` does the standard rescue:

1. Disable the I2C peripheral and switch SCL and SDA to plain GPIO.
2. Toggle SCL up to 9 times until SDA is released.
3. Generate a STOP condition.
4. Reconfigure the pins and re-initialize the peripheral.

## Sensor and OLED on one bus

Adding the OLED face brought a second problem. It worked, but the sensor loop got slower and the balancing worse.

### The two kinds of traffic are very different

| | MPU6050 read | OLED full-screen refresh |
|---|---|---|
| Bytes per transaction | 2 to 6 data bytes | 1024 data bytes (128 × 64 ÷ 8) |
| Bytes on the wire (approx.) | ~5 to 9 | ~1030 |
| Time at 400 kHz | about 0.2 ms | about 23 ms |
| Time at 100 kHz | about 0.8 ms | about 93 ms |
| How often | Every control cycle | Only when the face changes |

Approximate: each byte takes 9 clock cycles (8 bits plus ACK), and the figures ignore start/stop overhead and clock stretching. Your measured times depend on the bus speed you set.

A sensor read is a quick question. A full frame refresh is about **100 times longer**, and it uses the same two wires.

### Why that hurts the control loop

1. **One bus, one conversation at a time.** I2C allows a single transaction at a time. While the framebuffer is going out, the IMU cannot be read.
2. **The HAL calls are blocking.** `HAL_I2C_Master_Transmit` does not return until the whole frame has been sent, so the CPU waits too. The control loop effectively pauses for the length of the refresh.
3. **The loop period jumps.** A normal cycle takes a few milliseconds, and a cycle with a redraw takes tens of milliseconds longer. The complementary filter integrates the gyro using `dt`, so a long cycle both delays the correction and makes that step's gyro integration larger. The balance controller sees an old angle at the moment it matters.
4. **Long transactions meet bus faults.** A long transfer is more exposed to noise than a short one, so the OLED traffic also raised the number of failed reads in a loose-wired build.

### What helps

| Approach | Idea | Cost |
|---|---|---|
| **Redraw only on change** (used in Edmond) | Draw the face when the fallen/normal state flips, not every cycle | Almost free, a few lines of edge detection |
| **Rate-limit** | Redraw at most every few hundred ms | Easy |
| **Partial updates** | Send only the changed page or region instead of all 1024 bytes | More code |
| **DMA or interrupt-driven transfer** | The CPU keeps running while the hardware sends the frame | Moderate, needs careful sequencing so sensor reads wait their turn |
| **A separate I2C bus** for the display | No sharing at all | Needs a free I2C peripheral and pins |
| **Faster bus clock** | Shorter transfers | Check that both devices support the speed |

Edmond's implementation:

```c
static uint8_t lastFaceState = 0xFF;          // forces the first draw

void updateFaceDisplay(uint8_t isFallen) {
    if (isFallen != lastFaceState) {          // draw only when the state changes
        if (isFallen) ssd1306_displayFallenFace();
        else          ssd1306_displayNormalFace();
        lastFaceState = isFallen;
    }
}
```

`updateFaceDisplay()` is called once per loop, outside the tipped branch, so the face also returns to normal after the robot is picked up.

## Lessons learned

- **Never trust a blocking call with `HAL_MAX_DELAY`.** One stuck bus can hang the whole system. Use a timeout and handle the failure.
- **Check every I2C transaction, not just the first one.** An unchecked read hands garbage to the rest of the code.
- **Print the error code in hex.** It turns "I2C is broken" into a specific cause.
- **Intermittent errors are usually electrical.** Solder it, shorten the wires, keep them away from motor wires.
- **Keep the last good value, but plan for a long outage.** It covers glitches, not dead sensors.
- **A shared bus is a shared budget.** A 1 KB display refresh costs about a hundred sensor reads. Update the display only when it changes.
- **Pin and peripheral choices matter early.** Check the pin alternate functions before assigning timers and I2C on the same pins.

## References

- STM32F3 HAL driver source, I2C error definitions: [`stm32f3xx_hal_i2c.h`](https://github.com/STMicroelectronics/stm32f3xx_hal_driver/blob/master/Inc/stm32f3xx_hal_i2c.h) (and the matching `Src/stm32f3xx_hal_i2c.c` in the same repository)
- STM32F303 reference manual (RM0316) and Nucleo-32 user manual (UM1956), from [st.com](https://www.st.com): I2C peripheral and board details

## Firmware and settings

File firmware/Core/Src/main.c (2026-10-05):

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
/* Includes ------------------------------------------------------------------*/

#include "main.h"

/* USER CODE BEGIN Includes */
#include <stdio.h>
#include <string.h>
#include <stdlib.h>
#include <math.h>
#include <stdbool.h>
#include "mpu6050.h"
#include "fit0450encoder.h"
#include "control.h"
#include "robot_state.h"

//SSD Display
#include "ssd1306.h"
#include "ssd1306_tests.h"

/* USER CODE END Includes */

I2C_HandleTypeDef hi2c1;

TIM_HandleTypeDef htim1;
TIM_HandleTypeDef htim2;

UART_HandleTypeDef huart2;

void SystemClock_Config(void);
static void MX_GPIO_Init(void);
void MX_I2C1_Init(void);
static void MX_TIM1_Init(void);
static void MX_USART2_UART_Init(void);
static void MX_TIM2_Init(void);
/**
  * @brief  The application entry point.
  * @retval int
  */
int main(void)
{

  /* MCU Configuration--------------------------------------------------------*/

  /* Reset of all peripherals, Initializes the Flash interface and the Systick. */
  HAL_Init();

  /* Configure the system clock */
  SystemClock_Config();

  /* Initialize all configured peripherals */
  MX_GPIO_Init();
  MX_I2C1_Init();
  MX_TIM1_Init();
  MX_USART2_UART_Init();
  MX_TIM2_Init();
  /* USER CODE BEGIN 2 */

  ssd1306_Init();
  MPU6050_Init();



  /* For Manual Calibration Using Jig
  float *resultAccel = getAccelerometerOffsets();
  float AxOffsetError = resultAccel[0];
  float AyOffsetError = resultAccel[1];
  float AzOffsetError = resultAccel[2];

  float *resultGyro = getGyroscopeOffsets();
  float GxOffsetError = resultGyro[0];
  float GyOffsetError = resultGyro[1];
  float GzOffsetError = resultGyro[2];
  */

  //Calibrated Values using Jig
  float AxOffsetError = -0.045f;
  float AyOffsetError = -0.003f;
  float AzOffsetError = -0.018f;
  float GxOffsetError = -4.092f;
  float GyOffsetError = 0.550f;
  float GzOffsetError = -1.389f;

  //Robot State Testing
  robotState_Init(AxOffsetError,AyOffsetError,AzOffsetError,GxOffsetError,GyOffsetError,GzOffsetError);

  //Setting Control Gains from MATLAB
  setControlGains(-0.402994051163913f,	-1.843426576803016f,	8.675976709154341f,	1.132655976543293f);

  //Starting timers for motor control
  HAL_TIM_PWM_Start(&htim1,TIM_CHANNEL_1);
  HAL_TIM_PWM_Start(&htim1,TIM_CHANNEL_4);
  __HAL_TIM_SET_COMPARE(&htim1,TIM_CHANNEL_1,0);
  __HAL_TIM_SET_COMPARE(&htim1,TIM_CHANNEL_4,0);

  //Start Encoder Timer
  HAL_TIM_Encoder_Start(&htim2, TIM_CHANNEL_ALL);

  /* USER CODE END 2 */

  /* Infinite loop */
  /* USER CODE BEGIN WHILE */
  while (1)
  {
    /* USER CODE END WHILE */

    /* USER CODE BEGIN 3 */
	  //New Control Loop Testing w/ Fall Detection
	  RobotState state = getRobotState();
	  updateFaceDisplay(state.tipped);
	  if (state.tipped) {
		 setPWMControl(0.0f);
	  } else {
		  float u = computeControlEffort(&state);
		  float duty = computeControlDuty(u, state.v);
		  setPWMControl(duty);
		  //Printing over UART
		  //printRobotState(&state);
	  }

  }
  /* USER CODE END 3 */
}

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


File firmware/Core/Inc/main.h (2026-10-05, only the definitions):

#define VCP_TX_Pin GPIO_PIN_2
#define VCP_TX_GPIO_Port GPIOA
#define SWDIO_Pin GPIO_PIN_13
#define SWDIO_GPIO_Port GPIOA
#define SWCLK_Pin GPIO_PIN_14
#define SWCLK_GPIO_Port GPIOA
#define VCP_RX_Pin GPIO_PIN_15
#define VCP_RX_GPIO_Port GPIOA

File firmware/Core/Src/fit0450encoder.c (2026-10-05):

//for robot_newtimers

#include <mpu6050.h>
#include <main.h>
#include <stdio.h>
#include <stdlib.h>
#include <string.h>
#include <math.h>

extern TIM_HandleTypeDef htim2;
extern UART_HandleTypeDef huart2;


//global variables
int16_t countsPerRound = 1920;
int8_t secPerMinute = 60;
char stringEncBuffer[128];

//Deadband parameters
int16_t inPWMmin = 0;
int16_t inPWMmax = 4096;
int16_t outPWMmin = 1352;
int16_t outPWMmax = 4096;

//static state variables for positon and motor measurements
static int32_t lastCount = 0;
static int64_t positionAccumulator = 0; //Keeps the absolute value of encoder counts
static uint32_t lastTick = 0;
static float measuredVelocity = 0.0f;
static float measuredPosition = 0.0f;
static const int encoderCountPerRev = 1920;
static const float wheelRadius = 65.0f; // Units: mm
static const float wheelCircumfrance = 2.0f*(float)M_PI*wheelRadius;
static const float linearDistanceConverter = wheelCircumfrance/1000.0f; //Units: m

void updateEncoderState(){
	//@brief: Samples encoder once for two count values between two timer intervals,
	//		  Computes a signed delta value to handle the 16-bit wrap around
	// 		  Keeps track of position accumulated and updates its position
	//		  Calculated velocity from elapsed time interval
	//		  Must be called before every Control Loop Iteration
	//inputs: void
	//outputs: void

	int32_t currentCount  = (int32_t)__HAL_TIM_GET_COUNTER(&htim2);
	int32_t delta = currentCount - lastCount; //Difference between current and past encoder readings

	//Prevention of wrap around for values beyond timers 16bit register

	if (delta > 32768) {
		delta -= 65366;
	} else if (delta < -32768)  {
		delta += 65536;
	}
	lastCount = currentCount;
	positionAccumulator += delta; //keeps track of absolute position

	//Grabbing Time interval between encoder samples
	uint32_t currentTick = HAL_GetTick();
	float dt = (currentTick - lastTick) / 1000.0f;
	lastTick = currentTick;

	if (dt > 0.0f){
		float revsCurrentSample = (float)delta / encoderCountPerRev;
		measuredVelocity = (revsCurrentSample / dt) * linearDistanceConverter;
	} else {
		measuredVelocity = 0.0f;
	}

	measuredPosition = ((float)positionAccumulator / encoderCountPerRev) * linearDistanceConverter ; //measured position in m

}

float getVelocityEstimate(){
	//@brief: returns latest computed Velocity
	//inputs:  void
	//outputs: velocity in revolutions per second (signed value)
	return measuredVelocity;
}

float getPositionEstimate(){
	//@brief: returns latest absolute wheel position relative to starting position
	//inputs: void
	//outputs: position in revolutions (signed, absolute, and relative to powering on.
	return measuredPosition;
}

void getEncoderCount(){
	//@brief: gets encoder pulse reading raw values
	//inputs: void
	//outputs: void
	static int32_t encoderCount = 0;
	static int32_t pastencoderCount = 0;

	encoderCount = (int32_t)__HAL_TIM_GET_COUNTER(&htim2);

	if(encoderCount != pastencoderCount){
		sprintf(stringEncBuffer, "Encoder Count: %ld \r\n", encoderCount);
		HAL_UART_Transmit(&huart2,(uint8_t*)stringEncBuffer,strlen(stringEncBuffer),100);
		pastencoderCount = encoderCount;
	}
}

/*
void getMotorSpeed(){
	//@brief: counts 1920 ticks of encoder which is 2pi radians and gets two time measurements to get motor speed in rad/s
	//inputs: void
	//outputs: void
	//1920 counts per round

	static int32_t encoderCount = 0;
	static int32_t pastencoderCount = 0;
	static int32_t getTickOld = 0;
	float dt ;
	const int encoderCountPerRev = 1920; //1920 counts per rotation of shaft
	float motorSpeed;
	float revolutions;

	encoderCount = (int32_t)__HAL_TIM_GET_COUNTER(&htim2);

	if(encoderCount >= encoderCountPerRev){
		dt = (HAL_GetTick() - getTickOld)/1000.0f;
		getTickOld = HAL_GetTick();
		revolutions = (float)encoderCount / encoderCountPerRev;
		motorSpeed =  (revolutions / dt) * 60.0f; //testing revolutions per minute

		sprintf(stringEncBuffer, "motorSpeed (rev/min): %.3f \r\n", motorSpeed);
		HAL_UART_Transmit(&huart2, (uint8_t*)stringEncBuffer, strlen(stringEncBuffer),100);
		__HAL_TIM_SET_COUNTER(&htim2, 0); //reset the hardware timer to 0
		pastencoderCount = 0;

	}else if(encoderCount != pastencoderCount){
		//sprintf(stringBuffer, "Encoder Count: %ld \r\n", encoderCount);
		//HAL_UART_Transmit(&huart2,(uint8_t*)stringBuffer,strlen(stringBuffer),100);
		pastencoderCount = encoderCount;
		}
}
*/



/*
void setMotorSpeed(int16_t PWM){
	//@brief: sets motor speed via PWM
	//inptus: PWM between 0->4096
	//outputs: void

	//error checking
	if(PWM > 4096){
		sprintf(stringEncBuffer, "PWM Input out of Range");
		HAL_UART_Transmit(&huart2, (uint8_t*)stringEncBuffer, strlen(stringEncBuffer),100);
		PWM = 0;
	}else{
	//__HAL_TIM_SET_COMPARE(&htim3, TIM_CHANNEL_1, PWM);
	}
}

void motorDeadBandTest(){
	//@brief: for finding deadband region
	//inputs: void
	//outputs: void

	for(int i = 0; i < 4096*0.5; i++){
		setMotorSpeed(i);
		HAL_Delay(50);
	}
}
*/

long mapDeadband(long PWM){
	//@brief Remapping the desired duty cycle so it is within the capabilities of the motor
	//input: input PWM value [0->4096] = [0->100%];
	//output: output PWM value [1352->4096] = [33->100%] Duty Cycle;
    if (PWM <= 0) {
        return 0; // truly no command -> motor off
    }
    return (PWM - inPWMmin) * (outPWMmax - outPWMmin) / (inPWMmax - inPWMmin) + outPWMmin;
}

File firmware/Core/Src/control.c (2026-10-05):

/*
 * control.c
 *
 *  Created on: Aug 25, 2026
 *      Author: dueli
 */

#include <mpu6050.h>
#include <main.h> //Including main will allow us to access all the functions used
#include <stdio.h>
#include <stdlib.h>
#include <string.h>
#include <math.h>


extern I2C_HandleTypeDef hi2c1;
extern UART_HandleTypeDef huart2;
extern TIM_HandleTypeDef htim1;
//extern TIM_HandleTypeDef htim3;

char stringBuffer[128];


int mapDutyCycle(float controlDutyCycle){
	//@brief Take in controlDutyCycle that corresponds with Torque and wheel velocity (-1.0f to 1.0f)
	//		 Translate that value to PWM signal from -65535 to +65535 where -1.0 = -65535 and +1.0 is 65535
	//
	//input: dutyCycle % between -1.0 and 1.0
	//output: PWM signal representative of PWM Required for a Given Torque

	//ARR Value
	const int32_t outPWMmax = 65535;

	//Clamping
	if (controlDutyCycle > 1.0f){
		controlDutyCycle = 1.0f;
	}
	if (controlDutyCycle < -1.0f){
		controlDutyCycle = -1.0f;
	}

	int32_t mappedValue = controlDutyCycle * (float)outPWMmax;
	//sprintf(stringBuffer, "PWM: %.3ld \r\n", mappedValue);
	//HAL_UART_Transmit(&huart2, (uint8_t*)stringBuffer, strlen(stringBuffer),100);

	return mappedValue;

}

void setPWMControl(float controlDutyCycle) {
	//@brief Controls PWM inputs to Motor Driver and Direction of Wheels
	// 		 Reads the magnitude of the Duty Cycle
	// 	     Sets GPIO for Wheel Direction
	//		 Sets the PWM Pin with a duty cycle from 0->100%
	//inputs: Duty Cycle from +/- 65535
	//outputs
    int PWMMagnitude;
    PWMMagnitude = abs(mapDutyCycle(controlDutyCycle));

    // Check PWM
    if (controlDutyCycle > 0){
        HAL_GPIO_WritePin(GPIOA, GPIO_PIN_10, 1);
        HAL_GPIO_WritePin(GPIOA, GPIO_PIN_12, 0);

        //Test Prints
        //sprintf(stringBuffer,"Forward Direction \r\n");
        //HAL_UART_Transmit(&huart2, (uint8_t*)stringBuffer, strlen(stringBuffer),100);

    } else {
        HAL_GPIO_WritePin(GPIOA, GPIO_PIN_10, 0);
        HAL_GPIO_WritePin(GPIOA, GPIO_PIN_12, 1);

        //sprintf(stringBuffer,"BackwardDirection \r\n");
        //HAL_UART_Transmit(&huart2, (uint8_t*)stringBuffer, strlen(stringBuffer),100);
    }

    __HAL_TIM_SET_COMPARE(&htim1, TIM_CHANNEL_1, PWMMagnitude);
    __HAL_TIM_SET_COMPARE(&htim1, TIM_CHANNEL_4, PWMMagnitude);

    //sprintf(stringBuffer,"PWM Magnitude: %.d \r\n", PWMMagnitude);
    //HAL_UART_Transmit(&huart2, (uint8_t*)stringBuffer, strlen(stringBuffer),100);

}


/*
void setPWMPitchControl(float filtValue) {
    int PWMmagnitude;
    float PWM;

    PWMmagnitude = map(filtValue);
    PWM = PWMmagnitude;

    __HAL_TIM_SET_COMPARE(&htim1, TIM_CHANNEL_1, PWM);
    __HAL_TIM_SET_COMPARE(&htim1, TIM_CHANNEL_4, PWM);

    // Check filtValue's sign, NOT the PWM magnitude
    if (filtValue > 0){
        HAL_GPIO_WritePin(GPIOA, GPIO_PIN_10, 0);
        HAL_GPIO_WritePin(GPIOA, GPIO_PIN_12, 1);
    } else {
        HAL_GPIO_WritePin(GPIOA, GPIO_PIN_10, 1);
        HAL_GPIO_WritePin(GPIOA, GPIO_PIN_12, 0);
    }
}

int map(float pitchAngle){
	//@brief Maps accelerometer pitch range to pwm signal
	//input: Calculated Pitch Angle Range: +/- 40 Degrees otherwise clamped
	//output: PWM signal representative of pitch angle


	const float pitchMin = 0;
	const float pitchMax = 40.0f;
	const uint16_t outPWMmin = 0;
	const uint16_t outPWMmax = 65535;
	static uint16_t mappedValue = 0;
	//static float calculatedDuty = 0;

	//Clamping to maximum beyond 40 degrees
	if (pitchAngle > pitchMax || pitchAngle < -pitchMax){
		mappedValue = outPWMmax;
		//sprintf(stringBuffer, "PWM: %.3d \r\n", PWM);
		//sprintf(stringBuffer, "PWM: %.3f \r\n", calculatedDuty);
		//HAL_UART_Transmit(&huart2, (uint8_t*)stringBuffer, strlen(stringBuffer),100);
	}else if (pitchAngle > 0){
		mappedValue = (pitchAngle - pitchMin) * (outPWMmax - outPWMmin) / (pitchMax - pitchMin) + outPWMmin;
		//sprintf(stringBuffer, "PWM: %.3f \r\n", calculatedDuty);
		//HAL_UART_Transmit(&huart2, (uint8_t*)stringBuffer, strlen(stringBuffer),100);

	} else if (pitchAngle < 0){
		mappedValue = (-pitchAngle - pitchMin) * (outPWMmax - outPWMmin) / (pitchMax - pitchMin) + outPWMmin;
		//sprintf(stringBuffer, "PWM: %.3f \r\n", calculatedDuty);
		//HAL_UART_Transmit(&huart2, (uint8_t*)stringBuffer, strlen(stringBuffer),100);
	} else {
		mappedValue = 0;
		//sprintf(stringBuffer, "PWM: %.3d \r\n", PWM);
		//HAL_UART_Transmit(&huart2, (uint8_t*)stringBuffer, strlen(stringBuffer),100);
	}

	//calculatedDuty = ((float)mappedValue / (float)outPWMmax)*100.0f;

	return mappedValue;
	//__HAL_TIM_SET_COMPARE(&htim3,TIM_CHANNEL_1,PWM);
	//sprintf(stringBuffer, "PWM: %.3d \r\n", mappedValue);
	//HAL_UART_Transmit(&huart2, (uint8_t*)stringBuffer, strlen(stringBuffer),100);

}

*/

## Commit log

2026-10-05 Document pinout and connections for STM32 Nucleo-F303K8
    Added detailed pinout information for STM32 Nucleo-F303K8, including connection tables, I2C bus details, motor driver specifications, power supply information, wiring notes, and a bill of materials.
2026-10-05 Update wiring notes for I2C connections
    Clarified wiring notes regarding I2C failures due to vibrations and cheap headers.
2026-10-05 Update README to remove main loop flowchart
    Removed detailed flowchart of the main loop from the README.
2026-10-05 Revise README for flashing code and gyro calibration
    Updated instructions for flashing new robot code and clarified gyro calibration steps.
2026-10-05 Update known limitations in README
    Clarify limitations regarding encoder and power supply.
2026-10-06 Expand README with mechanical design details
    Added detailed mechanical design information, including assembly notes, mass properties, and fastener specifications.
2026-10-06 Document accelerometer calibration jig and usage
    Added section on accelerometer calibration jig with usage instructions and axis convention details.
2026-10-06 Insert calibration jig image in README
    Added an image of the calibration jig to the README.
2026-10-06 Add M3 Heat-Set Inserts to README
2026-10-07 Revise calibration jig file names in README
    Updated file references for calibration jig in README.
2026-10-07 Add description of digital filters used in STM32
2026-10-07 Add references section to digital filters documentation
2026-10-07 Enhance EMA Filter section in digitalfilters.md
    Added a description for the EMA Filter and included an image.
2026-10-07 Add reference to Complementary Filter video
2026-10-07 Improve formatting in digitalfilters.md
    Updated formatting and added section headers in the digital filters documentation.
2026-10-07 Fix formatting and typos in digital filters documentation
2026-10-07 Enhance digital filters documentation with new sections
    Added a new section for IIR Filters and included code examples for EMA and Complimentary Filters. Updated references for additional resources.
2026-10-07 Fix duplicate image in digital filters documentation
    Removed duplicate image tag for EMA Filter in documentation.
2026-10-07 Implement pitch angle estimation with filtering
    Added mpu6050_getAccelPitchAngle function for pitch angle estimation using accelerometer data and digital low-pass filtering.
2026-10-07 Update digitalfilters.md with drawbacks of filtering
    Added drawbacks section discussing the impact of filtering on computation delays and system performance.
2026-10-07 Add hyperlinks to digital filter references
    Updated references to include links to YouTube videos.
2026-10-07 Correct grammatical error in digital-filters.md
2026-10-07 Document I2C debugging and sensor reliability
    Added comprehensive guide on I2C debugging and sensor reliability for Edmond's MPU6050 and SSD1306 setup, including error codes, troubleshooting, and performance optimization strategies.
2026-10-07 Add custom motor driver and PCB to project tasks

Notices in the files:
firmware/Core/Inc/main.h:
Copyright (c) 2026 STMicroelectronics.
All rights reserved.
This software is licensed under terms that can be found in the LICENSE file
